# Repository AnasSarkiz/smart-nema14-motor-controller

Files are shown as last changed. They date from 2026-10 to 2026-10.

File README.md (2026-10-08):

# Active routing — 0.0.53-alpha.0

Read `docs/REV53-LOGIC-POWER-ESCAPES.md`. The canonical native replay retains
all56/120 complete nets, with240 required opens,128 tracks,82 ordinary0.30/0.45mm
full through vias,five manifested TypeVII thermal vias and seven filled regions.
Native other-errors:0; unchanged strict and filled-copper clearance failures:0;
GND remains one physical network. Original purchased definitions, all165 fitted
model transforms, capacitor placement, motor and carrier are preserved.
The complete USB_VDD bypass/return geometry is screened; V3V3 remains incomplete.
Continue3.3V/core power,PD/eFuse controls,USB pair and ALL remaining physical nets.
Publication is WIP; loaded power/USB/thermal,complete CAM,quote and hardware tests
remain pending. Do not stop at this step. PROTOTYPE FABRICATION READY:NO.

---

# Active routing — 0.0.52-alpha.0

Read `docs/REV52-VM-POWER-ROUTING.md`. Qualified power019 joins56/120 required
nets, including every RAW/protected-VBUS/VM terminal and all prior54 nets.
265 opens,112 tracks,79 ordinary0.30/0.45mm full through vias,five manifested
TypeVII thermal vias,eight native filled regions. Native other-errors:0; strict
and filled-copper clearance failures:0; GND remains one physical network.
Keep all supplier imports/models/placement unchanged. Continue3.3V and core
power,PD/eFuse controls,USB pair with return path,then ALL remaining connections.
Accepted main routes are phase0; VM fanouts phase2; new selected-net routing
is phase3 so existing power copper is a frozen obstacle. Publication is WIP;
loaded power/USB/thermal,complete CAM,assembly quote and hardware tests pending.
Do not stop at this checkpoint. PROTOTYPE FABRICATION READY:NO. No board order.

---

# Smart NEMA 14 Motor Controller

Revision **0.0.53-alpha.0 — WIP prototype** uses **RP2040** and **two USB-C ports**:
`J_USB` supplies motor power through STUSB4500 USB-PD; `J_DATA` connects the
computer's USB data. The board is 35 × 35 mm, four layers, with the original
STEPPERONLINE 14HM11-0404S motor and front carrier. Motor control is open loop.

Configure and read back STUSB4500 NVM for two active sink PDOs: 5 V bootstrap
and preferred 15 V / 1.5 A. Deactivate the factory 20 V PDO. The hardware
interlock combines the 15 V indication, live sink path, MCU request and logic
supervisor. Factory settings alone do not establish a 15 V motor contract.
Computer VBUS only supplies its presence-sense divider; computer power cannot
power the controller or motor. The POWER port must also be connected.

The checked copper connects **56/120 required nets**, including all raw/protected VBUS and all fifteen motor VM terminals: **128 traces, 82 ordinary
0.30 mm drill / 0.45 mm pad through vias, five filled/capped TMC2209 thermal
vias and seven native filled regions**. It has **240 open-port errors**, zero other
native errors and zero independent copper-clearance violations. Routing and
loaded power, USB, thermal and fresh manufacturing qualification continue.
**PROTOTYPE FABRICATION READY: NO. Not hardware tested.**

All 166 electronic references have purpose notes on eleven native A4 sheets;
165 are fitted (R50 is optional). Original official JLCPCB definitions and
OBJ/STEP models are preserved. Actual assembly, model registration and bounded
connector/cable checks pass. See [current routing evidence](docs/REV53-LOGIC-POWER-ESCAPES.md),
[two-port electrical review](docs/REV50-TWO-PORT-ROUTING.md),
[15 V NVM programming](docs/STUSB4500-15V-PROGRAMMING.md), [validation](VALIDATION.md)
and [Cloud task](docs/cloud/TASK.md). The remaining imported TVS schematic
rotation finding is disclosed. Exact-part stock checks are snapshots, not a
customer PCBA allocation or assembly quote.

The lockfile pins Bun 1.3.9, tscircuit 0.0.2757, CLI 0.1.2257, core 0.0.2107,
native Pipeline9 0.0.962 and coherent released dependencies.

```bash
bash scripts/cloud-setup.sh
bash scripts/cloud-smoke.sh
bun run typecheck
bun run build
```

Setup/startup do not route. The intermediate build exits 1 while required opens
remain. Routing uses bounded native Pipeline9 batches and qualified saved source
paths, without supplier edits, generated JSON edits or weaker checks.

Public destinations: [GitHub main](https://github.com/AnasSarkiz/smart-nema14-motor-controller)
and [tscircuit](https://tscircuit.com/AnasSarkiz/smart-nema14-motor-controller--01a0fd9b).
Publication receipts identify exact matching source, Circuit JSON and CAD bytes.
No fabrication order is authorized.

---

## Historical revision 48 record

The following is preserved history. Its one-port architecture, counts, toolchain
and CAD limitations do not describe the current two-port revision.

# Smart NEMA 14 Motor Controller

Revision **0.0.48-alpha.0** — **RP2040 + autonomous STUSB4500 USB-PD**.
**Partially routed prototype. PROTOTYPE FABRICATION READY: NO. Not hardware tested.**

The user-requested redesign replaces STM32/TCPP01 with official RP2040,
external 2 MB QSPI flash, 12 MHz crystal and a dedicated STUSB4500 sink with
back-to-back P-channel power switches. The former MCU had UCPD hardware but
qualified PD firmware was absent; USB-C alone did not establish working PD.
The new controller negotiates autonomously using its factory sink PDOs.
Firmware must qualify the actual contract before enabling the motor/current.

The CAN interface uses a new MCP2515 SPI controller and retains SN65HVD230.
A functional magnetic buzzer driver is added; TMP112 remains the I2C sensor.
Its sheet now includes the sensor, pull-ups, bypasses and buzzer circuit.
All **147 electronic references / 146 default fitted** have purpose notes on
nine native A4 sheets. Only R50, the optional CAN termination link, is DNP.

The board remains **35 x 35 mm, four layers**, with the original four
connectors, front carrier and exact **STEPPERONLINE 14HM11-0404S** single-front-
shaft motor. AS5600 stays removed; motor control is open loop.

See [the complete redesign and every review request](docs/RP2040-USB-PD-REDESIGN.md),
[current routing checkpoint](docs/REV48-ROUTING-CHECKPOINT.md),
[current validation](VALIDATION.md) and [Cloud task](docs/cloud/TASK.md).
Manufacturer pin/BOM and initial placement/model reviews permit routing.
Complete copper, power/USB/thermal/CAM qualification and hardware tests remain.
The full official schematic analyzer leaves one imported TVS rotation defect.
No purchased import, pad mapping, model, DRC or TypeScript rule is patched.

Fresh native [Circuit JSON](dist/index/circuit.json) contains **97 traces,
79 ordinary through vias and8 native ground pours**. **64 of108 required nets** have
one independently measured physical copper island. Native checking still
reports **227 open-port errors**, with zero other native errors and zero strict
copper/drill/edge/keepout violations in this partial build. The build exits1
because connectivity remains incomplete. It is not ready to order.
Old STM32 copper is preserved historically and deliberately cannot be replayed
against the new RP2040 pin selectors. Revision 43 Gerbers/exports cannot
manufacture this revision.

The reproducible lockfile uses Bun1.3.9, tscircuit0.0.2750 / CLI0.1.2254 /
core0.0.2105 / native Pipeline9 0.0.962 with coherent released dependencies.
Frozen installation succeeds through the official registry mirror with normal
TLS/integrity. No substitute router, dependency patch or proxy bypass is used.
Saving a Cloud draft alone does not activate its network policy.

All12 ICs and all146 fitted genuine STEP models pass actual CadQuery import,
solid validity and export/reimport. Current internal placements pass actual mounted146-mesh nominal envelope checks.
The native placement screen retains three orientation suggestions; they remain
explicit alongside the one imported TVS schematic-style finding.
All54 exact part numbers have positive official JLCPCB stock/SMT availability
checked2026-10-07 12:01UTC; customer allocation remains pending. The5-board
fitted-part baseline is$27.261 per board, excluding PCB, assembly/loading fees,
supplier losses, shipping/tax, carrier and motor. This is not a delivered quote.

```bash
bash scripts/cloud-setup.sh
bash scripts/cloud-smoke.sh
bun run build
bun run typecheck
```

Installation/startup do not route. Routing uses one bounded selected-net
native Pipeline9 job at a time on Linux through scripts/run-cloud-routing.py,
plus supported native saved manual paths. All56 current vias measure0.30mm
drill /0.45mm pad and span all four layers. Via-in-pad is disabled. Outer power,
complete loaded widths and USB coupling/return require copper qualification.

The standard JST programmer's five-pin order and protected SWD paths are
preserved. Its VOUT is isolated; independently power the target and use an
RP2040 programming target. The 38 wiring assertions pass; successful flashing
has not been tested.

Public destinations: [GitHub main](https://github.com/AnasSarkiz/smart-nema14-motor-controller)
and [tscircuit](https://tscircuit.com/AnasSarkiz/smart-nema14-motor-controller--01a0fd9b).
Publication receipts identify the exact successfully uploaded revision; a
local version number does not prove publication. The runtime packet includes
unchanged official OBJ/STEP dependencies and matching native JSON, excluding
old experiments. Full historical evidence and the tscircuit skill remain in Git.
No fabrication order is authorized.

The mounted native GLB has an empty J_SWD mesh after intermittent HTTP503
from the standard programmer's original model URL. The mechanical guard
reports145/146 fitted meshes measured, no carrier/fastener/pair collisions
among those145, and **fails** on the missing connector. A successful builder
exit does not qualify complete CAD rendering or fit. Original supplier models
and URLs are retained; no placeholder or changed component is substituted.

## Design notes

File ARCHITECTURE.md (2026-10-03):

# Current architecture — revision 16

Exact 14HM11-0404S, open-loop default. USB4110/C5143397 → TCPP01/C1121848 and STL11N3LLH6 → TPS26600RHFR/C2155767 → VM → TMC2209 and AP63203 3.3 V buck. Independent OUT rating allows reverse-blocked motor rail on USB removal; board is not rated 60 V. Isolated EFUSE_RTN is distinct from GND. Two 24 kΩ resistors select 0.50 A bootstrap /1.00 A contract-enabled current screen via low-voltage-specified DMG1012T-7. Motor sense pair is 1 Ω, 0.25 W; 10k/10k VREF yields about 0.32 A peak, conservative 0.34245 A screen. Two Panasonic 100 µF/35 V bulk capacitors, manufacturer-recommended buck capacitors and close bypass sites are retained.

Hardware pulls ENN high and CAN RS high at reset. Native MCU UCPD firmware is required for PD; TCPP only protects the port. Bootstrap allocation ≤150 mA at 3.3 V from a PD charger/dock advertising ≥1.5 A at 5 V. Motion only after qualified ≥1.5 A contract at 9/12/15/20 V, max source 21 V. External ports export signals/grounds, not 3.3 V power. SWD and VBUS sensing use powered-off-safe TMUX1511 gated by supply supervisor. U4/C6 and CAN termination link R50 are DNP by default. No rear encoder or rear screw mounting is claimed.

Four-layer 35×35 mm PCB mounts to four separate front-flange carrier supports. Exact official motor/USB models and unmodified supplier electronics are preserved. The configured native routing targets remain disabled in revision 16; actual copper is the next review. See VALIDATION.md, BOM-CURRENT.md and mechanical/POWER-CORNER-REVIEW.md for current limits/evidence. Firmware and physical tests remain pending.

## Historical architecture notes — earlier draft values and unresolved paths below are superseded by the current source

# Current revision 0.0.9-alpha.0 update

Selected motor: STEPPERONLINE 14HM11-0404S; 0.4 A/phase, 25 ohms,
24 mH, 0.9° (400 full steps/revolution), single front shaft. Previous motor
ratings/current-limit proposals and rear encoder mechanics below are retired.
No firmware current limit is implemented or tested. Optional AS5600 electrical
draft remains while feedback selection is pending. Motor attachment is blocked
pending rear fastener specification or a qualified carrier. Electronic supplier
imports and partial connectivity are unchanged; USB footprint/protection blockers
remain. See [current validation](VALIDATION.md).

## Previous electrical draft and historical motor proposals

# Architecture - partial schematic draft, not approved

## Power and startup

USB-C connector -> protected sink power path -> motor VM and 3.3 V buck.
Investigate the STM32G0B1 UCPD peripheral with TCPP01-M12 protection; retain
native PD as the proposed architecture. The TCPP01 is protection, not a
standalone PD-negotiation controller. MCU firmware must negotiate contracts.

Default USB 5 V must boot logic while the motor remains disabled by a hardware
pull-up on TMC2209 ENN. Firmware should select an offered PD contract,
prefer 12 V or 15 V when available, verify measured VBUS and negotiated current,
configure the driver and only then permit motion. Requesting 12 V cannot
guarantee that a particular source offers it. Support 9 V and 20 V where
offered. 5 V fallback is logic-only with ENN high; the chosen standard TMC2209
internal-regulator circuit requires at least 5.5 V. Never bridge 5VOUT to VM
in this multi-voltage design.

The startup supply, TCPP dead-battery behavior, MOSFET orientation, inrush,
connector-side capacitance, voltage sensing, overvoltage threshold and power
discharge still need a complete schematic and review. A bulk motor capacitor
must not be connected indiscriminately across unnegotiated VBUS; assess
isolating it with a controlled power path. Do not assume a MOSFET plus TVS
provides complete USB PD or regeneration protection.

The logic regulator draft now uses imported Diodes AP63203WU-7, C780769,
fixed 3.3 V with a 32 V operating input limit, 3.9 uH C19947652 / Bourns SRN6028C-3R9M, 10 uF/50 V
input, 100 nF bootstrap and two nominal 22 uF/25 V output capacitors.
Its VBUS_INRUSH_OUT input is not supplied yet. Upstream inrush/reverse-current
protection, effective capacitance, transient tests and thermal review remain gates.

## MCU and interfaces

Candidate STM32G0B1CBT6, C2847904, LQFP48/7 x 7 mm. The manufacturer
datasheet confirms USB FS, UCPD and FDCAN in this family. The 48-pin package
exposes UCPD1 CC pins PA8 and PB15 and USB PA11/PA12. The simultaneous candidate pin allocation is recorded in
references/MCU-PIN-PLAN.md. CAN uses PB5/PB6, preserving USB PA11/PA12.
MCU supply/reset, I2C, CAN and motor UART/STEP/DIR/ENN/DIAG connections
are instantiated. USB/CC frontend is now wired as a draft; downstream power, SWD and external IO remain unfinished.

Use MCU-generated STEP/DIR/ENN, UART and DIAG with the TMC2209. Receive
external STEP/DIR and limits through MCU inputs with defined pull states,
protection and documented logic levels. Do not short external STEP/DIR
drivers directly to actively driven MCU outputs.

Candidate CAN transceiver: TI SN65HVD230DR, C12084, 3.3 V. The imported part is instantiated in the CAN draft sheet
for classical CAN; no CAN FD data-phase support is claimed. Termination must
be selectable at endpoints. Connector pinout, protection and termination
switch remain unselected.

The C165948 USB-C connector draft carries PD and USB 2.0 data, with C94934
data ESD protection. Connector footprint approval is blocked by its difference
from the manufacturer drawing; C3020560 remains an unqualified alternative. Verify duplicated receptacle USB pins, return paths and the
final 90-ohm differential geometry against the chosen stackup.

## Programming

The official installed package exports `StandardJstSwdResetSide`, backed by
JST SM05B-SRSS-TB(LF)(SN), C136657. Its pinout is:

| Pin | Official signal |
| --- | --- |
| 1 | VOUT |
| 2 | SWDIO |
| 3 | GND |
| 4 | SWCLK |
| 5 | NRST |

**Pin 1 is programmer power output, not a confirmed passive VTREF input.**
The package describes a voltage selector. Resolve 3.3 V-only operation and
backfeed protection before connecting it to the USB-powered logic rail.
Verify the recommended series resistors and programming power arrangement
from the package's source/documentation. They have not been qualified.
No custom SWD connector is proposed.

## Motor current and temperature

0.3-1.0 A/phase is the typical target; 1.2 A/phase continuous is an intended
upper design target, **not a verified operating limit**. Resolve RMS versus
peak current conventions for the motor, driver configuration and advertised
limits. The current draft uses imported C5127775 / HoLRT1206-1W-180mR-1%, 180 mOhm,
1 W, 1%, giving nominal full-scale 1.149 A RMS / 1.477 A sine peak. This
conservative iteration targets no more than 1.0 A RMS in firmware, with 0.3 A
bring-up. It does not implement the approximately 1.2 A upper target. Exact
motor/nameplate convention, resistor tolerance/temperature, driver threshold
spread and actual thermal capability must be qualified before rating the board.

Provide the manufacturer-specified charge-pump capacitors, VIO and 5VOUT
decoupling, compact VM capacitance, grounded exposed pad, thermal vias and
ground-plane spreading. Select either an NTC/ADC network or a digital sensor
near the driver with firmware thermal shutdown and recovery rules.

A warm motor housing cannot be assumed to cool the driver. No numerical
1.2 A thermal qualification exists yet. Review the heat path, copper area,
ambient conditions and enclosure, then measure driver/PCB/motor temperatures
on an actual prototype. Determine a lower bring-up current before first motion.

Motor deceleration can return energy to VM. USB PD sources are not assumed
to absorb it. Define the load/inertia/speed range and size an energy absorption
or braking arrangement; TVS clamping voltage and energy must protect every
rail-connected component across tolerances.

## Encoder and mechanics

AS5600-ASOM, C79815, is the proposed optional bottom-side I2C encoder.
Its sensing center must align with the actual rear shaft and a diametrically
magnetized magnet. Verify the manufacturer's field-strength/air-gap limits,
package sensing location, magnet holder and assembly tolerance. The center
of a generic SOIC bounding box is not enough evidence.

The only modeled geometry is the requested 35 x 35 mm envelope. No holes
or shaft clearance have been guessed. STEPPERONLINE 14HS13-0804D-PG51 is a
possible reference because its page explicitly specifies a rear shaft and
rear screw holes, but it is a geared model and is **not the selected motor**.
The manufacturer's drawing has not been obtained/reviewed. Front NEMA hole
pitch cannot by itself qualify a rear mounting arrangement.

## Future route corrections

The installed props expose `pcbRouteCache` and native PCB trace/path APIs.
Once prior gates pass, retain each routed circuit JSON and its source/dependency
checksums before changing routes. Correct geometry in supported native source
or route-cache inputs, rebuild, then repeat shorts, clearances, drill-to-copper,
connectivity and visual checks. Never edit Gerbers or erase DRC records to
conceal a fault. No routes exist in this revision to save or edit.

References and the limits of each review are in `references/SOURCES.md`.

## Revision 0.0.6-alpha.0 schematic progress

The old critical label-loss issues are resolved through released converter output,
with the original audit unchanged. Five native A4 sheets now implement:

- STM32 power/reset and I2C1/FDCAN2 pin connections with imported passives.
- AS5600 at 3.3 V: both supply pins tied together, 100 nF, 4.7 kOhm I2C pull-ups,
  DIR grounded, OUT unused and PGO retaining its internal pull-up. This draft
  supports volatile configuration/readout only, not OTP programming.
- AP63203 with imported passives and a reviewed preliminary inductor ripple calculation.
- TMC2209, two 180 mOhm sense resistors, charge pump, 5VOUT/VIO/VM decoupling,
  200 uF nominal motor bulk, 10 kOhm ENN pull-up, STEP/DIR pull-downs, UART
  TX 1 kOhm and 5VOUT-derived VREF divider. No PCB thermal-via geometry yet.
- SN65HVD230 with 100 nF, RS grounded for high-speed classical CAN, VREF unused.
  The connector, ESD and selectable termination are still pending.

The regulator and motor support networks are present but their protected supply
inputs have no source yet. The separate VM input prevents a draft from implying
that the motor bulk can be connected directly to USB VBUS. Unwired MCU pins reserved for unfinished
blocks are intentionally visible; they are not declared as unused. Only actually
unused GPIO are marked no-connect and must be set to analog mode in firmware.
C2's nominal 4.7 uF must be checked for effective capacitance under bias.
No PCB coordinates are assigned. Encoder bottom-side intent does not establish
shaft alignment; all previews use PCB generation disabled.

TCPP physical pin 6 CTRLVBUS is the analog OVP divider input, not an MCU
control output. The pin plan was corrected before any such wiring was created.
TI TPS259470LRPWR / C3662793 was imported as an unused power-path candidate;
its presence does not qualify or implement the USB power path.

## Revision 0.0.7 USB frontend

See references/USB-PD-REVIEW.md for implemented pin connections, dead-battery
sequence, C0G replacement, OVP tolerance screen and explicit component blockers.
The protected output is not connected to buck or motor. No startup, PD contract,
overvoltage, reverse-current, current-limit or regeneration behavior is qualified.

## Revision 0.0.8 motor lock

Phidgets 3323_0 / 35STH40-1004B is the sole target motor. Motor rating
is 1 A/phase, superseding the earlier 1.2 A target. Until waveform/current
and thermal qualification, conservative proposed driver limits are 0.3 A RMS
bring-up and 0.7 A RMS maximum (approximately 0.99 A sine peak). These
limits are not implemented or verified firmware. Exact rear drawing and
original STEP are retained; the STEP's 4.0 mm rear shaft differs from the
drawing's 3.9 mm maximum. Diagnostic-only native assembly, proposed hardware
and remaining gates are described in mechanical/REVIEW.md. Routing is disabled.

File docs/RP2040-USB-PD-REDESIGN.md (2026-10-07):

# Active two-port continuation

The current RP2040 design requires separate 15 V motor POWER and COMPUTER
DATA USB-C ports. See [revision50](REV50-TWO-PORT-ROUTING.md) and the
[STUSB4500 programming procedure](STUSB4500-15V-PROGRAMMING.md). Earlier
one-port factory-PDO statements below are historical.

---

# Active routing — 0.0.47-alpha.0

Read docs/REV47-ROUTING-CHECKPOINT.md, VALIDATION.md and the manufacturer review
in docs/REV45-PRE-ROUTING-REVIEW.md. Current canonical copper connects54/108 nets:
85 tracks,56 ordinary0.30/0.45mm through vias,nine pours and249 open ports;
zero other native errors, native shorts or strict copper violations. GND has
one physical network. CAN TX/RX and one top-only motor winding are now saved.
Continue one bounded selected-net Pipeline9 job at a time, save qualified source
paths and correct actual DRC manually. Input-only diagnostics and public SDK
pre-repair capture never imply solved or qualified routes. All remaining54 nets,
loaded widths/USB/reference/thermal/fresh CAM and assembly quote remain open.
147 references/146 fitted genuine CAD records are unchanged from revision46.
Preserve original supplier imports/models/evidence, exact motor, connectors,
outline and carrier. Publish completed prototype steps with exact Circuit JSON
and CAD bytes under standing authorization. PROTOTYPE FABRICATION READY: NO.

---

# Historical revision46 continuation

# Active continuation — 0.0.46-alpha.0

Read docs/REV46-ROUTING-CHECKPOINT.md, VALIDATION.md and the manufacturer review
in docs/REV45-PRE-ROUTING-REVIEW.md. Current exact canonical copper connects
51/108 nets:82 tracks,52 ordinary0.30/0.45 mm through vias,nine pours and255
native open ports; zero other native errors or strict copper violations.
All147 references /146 fitted models /12 ICs pass actual CadQuery checks.
Fresh official stock checks pass all54 exact identities; allocation/quote pending.
Two C1570 30pF loads replace four parallel15pF loads and keep native CAN clocks
under10mm with zero vias. Three native placement orientation suggestions and
one disclosed imported TVS schematic rotation finding remain explicit.
Continue one changed bounded selected-net Pipeline9 job at a time, save qualified
source paths and correct actual DRC manually. Finish all copper, outer power
where feasible, USB return/impedance, current/thermal and fresh CAM/assembly
qualification. Preserve official imports/models/history, exact motor, outline,
four connectors and carrier. Publish completed prototype steps with matching
fresh Circuit JSON and original CAD hashes under standing authorization.
PROTOTYPE FABRICATION READY: NO. No fabrication order is authorized.

---

# Historical redesign notes

# Current RP2040 and autonomous USB-PD — 0.0.45-alpha.0

Read [the current manufacturer and routing review](REV45-PRE-ROUTING-REVIEW.md)
and [validation](../VALIDATION.md). Revision45 corrects the flash selection to
GD25Q16EEIGR/C2986331, USB terminations to27 ohm/C25100, adds the qualified-delay
RUN supervisor, and uses the correctly rated genuine B5819WS flyback clamp.
The coherent latest released toolchain installs and passes TypeScript. All53
exact JLCPCB identities have positive official stock/SMT snapshots; all12 ICs
and148 fitted genuine STEP models pass actual CadQuery validity/export checks.

The checked partial board has41/108 physically joined nets,61 tracks,28 ordinary
0.30/0.45mm through vias,0 pours and407 open-port errors. No other native error
or independent copper-clearance violation remains in this partial packet.
Both actual USB plug-orientation paths are connected; planar skew is0.409mm,
the ESD-to-termination trunk skew is0.195mm and MCUstub skew is0.100mm.
A supported native Bus applies the unchanged0.25mm limit to the actual two
trunks. Full plug paths retain the independent0.5mm limit. A branched connector
must not compare its short stub length with a different signal's entire trunk.
The long pair uses one common inner2 layer; actual coupling, via-barrel delay,
ground reference/impedance and complete routing/CAM remain unqualified.

The exact motor, four connectors, 35×35mm four-layer outline and carrier stay
unchanged. Only internal parts move for real USB escape/clearance defects;
original purchased definitions and model bytes are preserved. All149 references
have purpose notes on9 A4 sheets. The disclosed imported TVS orientation style
finding remains visible. The5-board fitted parts baseline is$27.27 per board,
excluding PCB/assembly/loading/supplier losses/shipping/tax/carrier/motor.
**PROTOTYPE FABRICATION READY: NO.** No order or hardware result is claimed.

The following revision44 description is preserved as historical evidence;
its old flash,33 ohm resistors, flyback, blocked toolchain and unrouted counts
are superseded by the current review above.

---

# Historical RP2040 and autonomous USB-PD — revision 0.0.44-alpha.0

This is a new, **unrouted prototype**, replacing the revision 43 STM32 MCU and
TCPP01 protection architecture at the user's request. The former STM32 had a
UCPD peripheral, but the repository did not contain qualified PD negotiation
firmware. A USB-C connector or TCPP01 alone did not establish working USB-PD.

## Actual circuit change

U1 is official RP2040 / C2040, with external 2 MB W25Q16JVUXIQ / C2843335 boot
flash, a 12 MHz ABM8-272-T3 / C20625731 crystal, supply bypasses, a 1.1 V internal
regulator reservoir and two 33 ohm USB data resistors. GPIO29 is unused. RUN is
pulled up; SWD is physical pin 25 and SWCLK pin 24. There is no BOOTSEL button in
this revision. Flashing via SWD and boot behavior still require firmware and
hardware testing.

U3 is official STUSB4500QTR / C2678061: an autonomous USB-PD sink on CC1/CC2,
with dead-battery connections, I2C address 0x28, bypasses, alert, reset and an
actual controlled back-to-back P-channel load switch. Q_PD_IN and Q_PD_OUT use
unchanged official STL8P4LLF6 / C222138 imports, common sources and common gates.
A 100 kohm gate-to-source resistor defaults the pair off; 22 kohm connects the
gate to the controller's active-low VBUS_EN_SNK output. The ST reference and
MOSFET manufacturer pin tables were read; complete protection review is open.

Factory sink PDOs are **5 V/1.5 A, 15 V/1.5 A and 20 V/1 A**. They are not a
promise that the connected charger supports them. Firmware must read the
actual negotiated RDO and measured VBUS before enabling higher current or the
motor. POWER_OK3 alone is insufficient. A preferred 15 V operating profile
needs qualified NVM configuration and charger compatibility. Do not enable a
1 A nominal eFuse limit against a 1 A contract without worst-case tolerance and
logic/motor current margins. The retained input limiter boots at nominal 0.5 A.

VBUS sensing uses a 1 kohm Panasonic ERJ-P08F1001V / C4261071 resistor. Two
parallel resistors of that same part discharge VM (effective 500 ohm). Each is
nominally 0.66 W; pulse, temperature derating and bulk-capacitance/discharge
timing qualification are pending. VDD has 470 ohm input filtering. The existing
25 V TVS and 40 V switch require a real transient coordination review against
the PD controller's limits. Nominal operation is not surge qualification.

RP2040 has no hardware CAN peripheral, so the existing CAN function now uses
official MCP2515T-I/ML / C96140 over SPI1 and a 16 MHz ABM8 crystal / C179641.
The SN65HVD230 transceiver and optional endpoint termination are retained.
Each crystal leg has two parallel 15 pF official capacitors (30 pF total);
crystal load/stray capacitance, oscillator startup, 3.3 V SPI clock limits and
bit timing need manufacturer and hardware qualification.

The formerly sparse I2C sheet now contains TMP112 at 0x48, its bypass/alert and
shared pull-ups, plus a functional C94598 MLT-5020 magnetic buzzer circuit:
GPIO25 PWM, official DMG1012T low-side switch, 100 ohm gate resistor, 100 kohm
default-off pull-down, 1N4148WS flyback clamp and 1 uF local bypass. This is a
circuit addition; drive current, acoustic performance, rail budget and carrier
clearance are not yet qualified. No duplicate temperature sensor or AS5600 is
added; the selected single-front-shaft motor remains open loop.

## Firmware interface

| RP2040 GPIO | Function |
| --- | --- |
| 0 / 1 | TMC UART TX / RX |
| 2 / 3 / 4 / 5 | TMC STEP / DIR / active-low enable / DIAG |
| 6 / 7 | I2C1 SDA / SCL (TMP112 0x48, STUSB4500 0x28) |
| 8 / 9 / 10 / 11 | SPI1 MISO / chip select / clock / MOSI |
| 12 / 13 | MCP2515 active-low interrupt / CAN transceiver standby |
| 14 / 15 / 16 | External STEP / DIR / active-low enable |
| 17 / 18 | Limit inputs |
| 19 / 20 | PD active-low alert / active-high reset |
| 21 / 22 | eFuse active-low fault / high-current request |
| 23 / 24 / 25 | Status LED / fault LED / buzzer PWM |
| 26 / 27 / 28 | VBUS ADC / PD POWER_OK3 / temperature alert |
| 29 | Unused |

Keep ENN high, high-current request low, buzzer off and CAN in standby at
reset. PD reset is active high and has a physical pull-down. The existing
standard JST programmer's VOUT stays isolated from target power; the target
must be powered independently. Its five-pin order and protection remain.
The updated independent 38-assertion check verifies wiring, **not successful
physical programming**. Use an RP2040 SWD/OpenOCD target, not STM32 firmware.

## Every review request and its actual status

| Review | Result / remaining work |
| --- | --- |
| RP2040 standardization | Implemented with genuine imports, flash and crystal; firmware and full manufacturer qualification pending. |
| Actual USB-PD | Dedicated autonomous STUSB4500 circuit implemented; NVM/contract/current/transient and physical tests pending. |
| Schematic readability | Nine functional A4 sheets, 147 purpose notes; sparse pull-up sheet fixed. Full official analyzer leaves one imported TVS rotation defect, not suppressed. |
| Standard USB-C symbol | Native standard symbol and all 16 purchased pad/pin groups checked. |
| JLCPCB availability | 147 exact supplier identities / 146 default fitted. Fresh official search has incomplete responses due HTTP 503; historical and initial candidate stock is not assembler reservation. |
| Placements and component correctness | New placement is checked natively and revised to improve actual bypass/crystal proximity. Manufacturer verification, route inductance/lengths and 3D fit remain gates. |
| Ordinary vias 0.30 / 0.45 mm | Configured through-via policy with via-in-pad disabled. There are zero generated vias: no claim of routed compliance. |
| No blind/buried vias | No vias yet. Verify every actual span after routing. |
| Power wires on outer layers | Required for new routing where feasible; no power traces exist yet. Old inner-power copper is historical. |
| Buzzer and I2C sensor | Complete source circuit added; retained TMP112 sensor. Drive/power/mechanical and routing qualification pending. |
| No shorts / opens / DRC | Placement build and explicit shorts screen reviewed separately. Explicit connection checks expose the missing new routes; board connectivity is incomplete. |
| Trace widths, power and USB | New copper, stackup, differential routing/return, current/thermal and regenerative-energy review required. Prior revision 43 metrics do not apply. |
| All 3D models | Official model dependencies must accompany publication; current dependency coverage is checked separately from actual mechanical fit. |
| Minimum runtime / circuit JSON | Dedicated runtime packet excludes old routing experiments. Fresh native JSON is required in all three mirrors. Old imports, copper and evidence remain historical in Git. |
| Updated tscircuit | Latest registry versions researched. Full upgrade fails on published modelprinter dependency at blocked pkg.pr.new; original frozen pins retained, not substituted. |
| Push to tscircuit | Publish a clearly labeled unrouted prototype only after applicable checks; exact public file hashes and matching GitHub commit must be verified. |
| Ready to order | **NO.** Stages 2/3 remain in progress; no routing/fabrication/hardware approval follows from installation or a zero placement-error count. |

Manufacturer hosts and `pkg.pr.new` are saved in the environment draft, retaining
the package-manager preset and existing install/startup instructions. The
configuration tool says **requires_publish**: review/save in environment
settings, then publish the environment to apply the policy. A saved draft is
not effective runtime access. No proxy bypass, package substitution, credential
copy or TypeScript/DRC reduction is used.

The 35 x 35 mm four-layer outline, four connectors, front carrier and exact
STEPPERONLINE 14HM11-0404S are retained. Revision 43 routing modules, models,
context manifests and evidence are preserved historically. Replaying STM32
pin selectors against RP2040 is explicitly rejected. Previous Gerbers and
qualification ZIPs cannot manufacture this revision.

**PROTOTYPE FABRICATION READY: NO. No fabrication order is authorized.**

The mounted native GLB has an empty J_SWD mesh after intermittent HTTP503
from the standard programmer's original model URL. The mechanical guard
reports145/146 fitted meshes measured, no carrier/fastener/pair collisions
among those145, and **fails** on the missing connector. A successful builder
exit does not qualify complete CAD rendering or fit. Original supplier models
and URLs are retained; no placeholder or changed component is substituted.

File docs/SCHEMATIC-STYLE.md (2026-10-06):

# Schematic style review — 0.0.42-alpha.0

The user's UI screenshot shows eleven issues on 0.0.40. The full current
official analyzer also reproduces eleven issues on the canonical 0.0.41 JSON.
Revision 0.0.42 reduces that result to **one unresolved issue**, D_VBUS
orientation. No style rule, DRC threshold or imported definition is changed.

| Issue | Source correction |
| --- | --- |
| J_USB box width | Native USB-C wrapper width 1.65 instead of 1.70; all sixteen official pin groups retained |
| U8 inner pin-label collision | Board-owned schematic width increased to 1.80 |
| Six separated capacitor banks | MCU, motor, buck, USB and programming capacitor schematic positions brought closer together |
| U1 reset supply path | Reset pull-up/filter moved to the MCU's reset side |
| U8 ground path | Local native GND label; reset pull-up moved closer |
| Additional automatic U10 ground detour during iteration | Local native GND label |

These changes affect schematic drawing only. The preservation check compares
every purchased manufacturer-pin electrical partition, part/pin attributes,
every PCB element type, placement and CAD registration with 0.0.41. It ignores
generated identifiers while resolving physical-port references to their real
component and manufacturer pin. All 411 purchased pins and all physical PCB/CAD
records remain exact. Original supplier modules and local model bytes are
unchanged. There is no new autorouting search.

## Analyzer and repeatable checks

Official analyzer source:
https://github.com/tscircuit/circuit-json-schematic-placement-analysis/tree/3b42ebf254bb5d7343874d3ec1023cc63a7781ce
(package manifest 0.0.45). The complete default analysis is used, without issue
filters. Its own native issue artifacts are rendered for review.

The pinned CLI's schematic-placement command runs an older, smaller analysis;
its successful exit status does not mean the full UI style analysis is clean.
The current official source reproduces the reported USB width warning even
though the analyzer bundled into the installed checks exempts native USB-C.
The board-owned width correction passes the full analyzer without exemptions.

The UI imports its analyzer from `jscdn.tscircuit.com`. That host returns proxy
403 in this VM. An exact live CDN/browser result is **not** claimed. To enable
that additional check, add only `jscdn.tscircuit.com` in environment network
settings and retry; do not replace the existing allowlist or bypass the proxy.
The official GitHub analyzer source executes locally using the existing pinned
runtime dependencies; no board dependency or lockfile changes are needed.

Example isolated review checkout, from the repository root:

```bash
git clone https://github.com/tscircuit/circuit-json-schematic-placement-analysis.git .publication/style-analyzer
git -C .publication/style-analyzer checkout 3b42ebf254bb5d7343874d3ec1023cc63a7781ce
ln -s "$PWD/node_modules" .publication/style-analyzer/node_modules
bun scripts/check-schematic-style.mjs dist/index/circuit.json .publication/style-analyzer/lib/analyze-schematic-placement.ts /tmp/schematic-style.json
python3 scripts/check-schematic-preservation.py /tmp/rev41-circuit.json dist/index/circuit.json /tmp/schematic-preservation.json
```

Use the immutable 0.0.41 baseline JSON from commit
`9f7ca62d598f61154ac4be2bc9db2debd83678d1` for `/tmp/rev41-circuit.json`.
The full style command correctly exits **1** while D_VBUS remains unresolved;
its report retains every issue and does not turn a known failure into a pass.

## Remaining imported-symbol defect

D_VBUS is official ESDA25P35-1U1M / C1974707. Its imported React `<symbol>`
remains horizontal despite the already requested native `schRotation={270}`.
The installed core's schematic transform translates these React primitives;
it does not apply the requested chip rotation. Changing the rotation number or
wrapping it in a group does not supply the missing runtime rotation.
The existing unmodified import reproducer is
`scripts/imported-symbol-rotation.circuit.tsx`.

This needs a supported upstream core/importer repair before complete schematic
qualification. No custom replacement symbol, dependency patch or generated-JSON
edit is adopted. The physical purchased pins and footprint remain verified.
Some automatic value labels still overlap wires; a zero style count would not
by itself establish readability, electrical correctness or fabrication readiness.

All prior fabrication blockers remain: MCU sourcing, supplier silk/orientation,
uniform requested vias, outer-only power, full power/thermal and manufacturer
process/assembly qualification. Firmware and hardware tests remain pending.
**PROTOTYPE FABRICATION READY: NO.** No fabrication order is authorized.

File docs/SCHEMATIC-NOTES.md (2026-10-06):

# Schematic component explanations

Revision 0.0.40-alpha.0 explains every one of the 109 electronic references inside
the native schematic. Each A4 sheet has a right-side COMPONENT PURPOSE panel,
with values and a short description of each device, passive or connector.
U4/C6 are removed. R2/R3 remain for U9 temperature monitoring; R50 is the
optional CAN endpoint link (DNP, do not populate). The default fitted count remains 108.

Native USB-C standard symbols and the explanatory panels are retained. Revision
40 removes U4/C6 and their notes, renames Encoder to I2C, and reconnects shared
PCB bus/power/ground copper. Remaining purchased placements, pads and CAD are
unchanged. The original component imports and model assets remain intact.

All nine native renders were viewed; the coverage/layout check requires one
explanation per reference on its matching sheet and a panel clear of symbols,
net labels and wiring. TypeScript, format, native build, netlist, shorts, placement
and source checks pass. Existing 30 route-width and 24 supplier-pin metadata
warnings remain disclosed. The snapshot command records a new visual baseline.

Run `bun run test:schematic-notes` on fresh canonical Circuit JSON and
`node scripts/render-schematic-sheets.mjs` to reproduce the individual images.

- [MCU](../evidence/rev-0.0.40-alpha.0/schematic-MCU.png)
- [I2C](../evidence/rev-0.0.40-alpha.0/schematic-I2C.png)
- [CAN](../evidence/rev-0.0.40-alpha.0/schematic-CAN.png)
- [LogicPower](../evidence/rev-0.0.40-alpha.0/schematic-LogicPower.png)
- [MotorDriver](../evidence/rev-0.0.40-alpha.0/schematic-MotorDriver.png)
- [UsbPd](../evidence/rev-0.0.40-alpha.0/schematic-UsbPd.png)
- [Programming](../evidence/rev-0.0.40-alpha.0/schematic-Programming.png)
- [Interfaces](../evidence/rev-0.0.40-alpha.0/schematic-Interfaces.png)
- [InputPower](../evidence/rev-0.0.40-alpha.0/schematic-InputPower.png)

PROTOTYPE FABRICATION READY: NO. Supplier silk, four CPL orientations,
four sourcing/allocation gaps, stackup/plating/filled-via acceptance and complete
power/thermal qualification remain open. Hardware and programming are untested.

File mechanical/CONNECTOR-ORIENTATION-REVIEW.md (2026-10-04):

# Connector orientation review — 0.0.19-alpha.0

All four actual native 3D connector openings face outward. No electronic rotation or placement correction is required. Each connector is side entry; the whole connector body need not sit flush with the board edge. The plug must have a clear outward insertion and straight cable exit corridor.

| Reference | Exact connector / JLCPCB | PCB side / rotation | Cable exit viewed from above | Outer model setback from PCB edge | Remaining screened plug clearance |
| --- | --- | --- | --- | --- | --- |
| J_USB | GCT USB4110-GF-A / C5143397 | top / 0° | lower edge, −Y | −0.090 mm (slight protrusion) | 2.2331 mm |
| J_MOTOR | JST SM04B-GHS-TB / C189895 | top / 180° | upper edge, +Y | 3.2670 mm | 2.0643 mm |
| J_IO | JST SM10B-SRSS-TB / C160409 | bottom / 90° | right edge, +X | 0.8620 mm | 0.1643 mm |
| J_SWD | JST SM05B-SRSS-TB / C136657 | top / 90° | right edge, +X | 0.4625 mm | 1.0385 mm |

Setbacks measure the exported model's outer bound, not an independently dimensioned mouth datum. Rotation numbers alone do not establish opening direction. J_IO's generated bottom CAD rotation is Y=180°/Z=270°; its actual exported mouth was reviewed from both sides and points +X. The manufacturer's SH and GH side-entry drawings were rendered and inspected alongside the model views. GCT exact STEP registration and the imported footprint audits remain applicable.

All 111 current component placements and CAD registrations exactly match the mounted model input. Every connector SMT land matches, including the bottom layer. Fresh exact carrier/fastener versus all 111 mesh-envelope checks pass, and the constrained mating screen was rerun. The minimum I/O margin is 0.164285 mm after 0.40 mm static allowance and 0.135715 mm analytical load deflection; this is tight and needs a physical fit test with SHR-10V-S/AWG28. JST actual mating STEP models remain unavailable; the plugs are explicitly drawing-based clearance envelopes. USB overmold ≤12×7 mm; route wires straight outward beyond the reviewed envelope before bending. Do not bend them inward toward the motor or carrier.

The native placement check reports zero errors/warnings. Formatting and TypeScript pass. No purchased definition, footprint, pin mapping, placement, electronic wiring or saved copper changed. The prior five native checks and partial-copper audit remain applicable. This review does not complete the 88 unfinished connections, final copper/current/thermal/USB checks, CAM or physical tests. The design remains an untested routing prototype.

Evidence: `evidence/rev-0.0.19-alpha.0/connector-orientation/ORIENTATION-REVIEW.json`, four isolated opposite-view renderings, connector-access overview, rendered manufacturer drawings, exact input hashes and correspondence report. The overview uses native geometry without the PCB artwork texture, and omits the motor to expose the underside. The separate mounted assembly still contains the exact unchanged motor.

Reproduce the rendered review from a matching mounted export and current partial circuit:

```sh
.mechanical-venv/bin/python mechanical/render-connector-orientation.py --current-circuit evidence/rev-0.0.19-alpha.0/current-partial/circuit.json --mounted-circuit dist/mounted-assembly/circuit.json --glb dist/mounted-assembly/3d.glb --output-dir evidence/rev-0.0.19-alpha.0/connector-orientation
.mechanical-venv/bin/python mechanical/check-front-carrier.py
python3 mechanical/check-carrier-tolerance.py
.mechanical-venv/bin/python mechanical/check-mating-envelopes.py
```

The renderer asserts current placement/CAD/land correspondence before accepting historical mounted geometry. Rebuild mounted geometry if these assertions fail. Dist files are reproducible build outputs; hashes identify the exact inspected input. Rendered images are not physical photos or physical test evidence.

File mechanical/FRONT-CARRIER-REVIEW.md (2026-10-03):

# Front-flange carrier — revision 0.0.16-alpha.0

Unfabricated mechanical prototype for the exact STEPPERONLINE 14HM11-0404S. The manufacturer drawing and STEP are unchanged. Four front M3 holes on the documented 26 ±0.2 mm square attach the carrier. Motor rear structural screws remain untouched.

The 35 × 35 mm PCB has four Ø2.5 mm NPTH holes on a 30.5 mm square with all-layer 2.5 mm radius keepouts. The monolithic machined 6061-T6/T651 carrier has a 49.2 × 36.5 × 3 mm front plate, Ø24 mm pilot opening, Ø3.8 mm front bolt clearances, four direct 6 × 6 mm rails and Ø4.5 mm PCB support bosses. Motor rear/front datums are Z=-10/-38.2 mm; PCB midplane is Z=0 and support surface -0.8 mm. Returns end at -4.8 mm below the PCB. Proposed machining tolerance is ±0.05 mm.

The actual exported 111 component mesh envelopes clear the exact carrier and fastener solids by at least 1.000005 mm. There is no carrier/motor intersection. The fresh mounted rendering was inspected. The analysis includes fitted and DNP component bodies conservatively. Production component models, actual hardware installation and strength are not physically verified.

JLC04161H-3313 is ordered as 1.6 mm but the live manufacturer calculator displays 1.56 mm finished, ±10%. Calculations use minimum PCB thickness 1.404 mm, and include the 1.6 mm rendering offset in the clearance allowance. A single rail carries the entire declared 20 N cable/board load in the cantilever screen. Conservative combined rail/arm/PCB deflection is 0.1357 mm and section stress safety factor 10.81. FR4 modulus is an engineering allowance, not a laminate guarantee. This is not FEA, fatigue qualification or a physical load test.

Permitted hardware envelopes: M2×5 length 5 ±0.2 mm, head ≤Ø3.8 ×1.6 mm, custom washer Ø4.5/Ø2.2 ×0.50 ±0.05 mm; M3×6 head ≤Ø5.5 ×3 mm. Screened M2 engagement is 2.484–3.396 mm versus 4.45 mm minimum thread envelope; front screw penetration is 2.75–3.25 mm versus the motor's 4 mm minimum available depth. These are dimensional procurement constraints, not a claimed purchased hardware model. Retention, preload, torque, insulation and physical installation remain Stage 7 tests.

Drawing-based conservative mating envelopes pass after an additional 0.40 mm static allowance plus the calculated load deflection. Remaining clearances: I/O 0.1643 mm, SWD 1.0385 mm, motor plug 2.0643 mm and USB 2.2331 mm. I/O: JST SHR-10V-S / SSH-003T-P0.2-H AWG28; SWD: SHR-05V-S / same contacts AWG28; motor: GHR-04V-S / SSHL-002T-P0.2 AWG26. USB cable overmold must fit ≤12 mm width ×7 mm thickness. Route all wires straight outward beyond the audited envelopes before bending. JST exact mating CAD requires an emailed download and was unavailable; these are explicit clearance envelopes from reviewed manufacturer drawings, not substitute exact component models.

Repeatable evidence: FRONT-CARRIER-AUDIT.json, CARRIER-TOLERANCE-SCREEN.json and MATING-ENVELOPE-AUDIT.json under evidence/rev-0.0.16-alpha.0/. The normal assembly is mounted-assembly.circuit.tsx; the +65 mm exploded view is inspection only. These checks authorize the next PCB routing stage for the bounded prototype; they do not approve hardware strength, arbitrary harnesses or fabrication orders.

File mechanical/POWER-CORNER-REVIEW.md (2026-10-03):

# Power disconnect and regeneration review — revision 16

Analytical screens only. Routing is disabled; no hardware test or fabrication readiness is claimed. Exact calculation inputs and results are in evidence/rev-0.0.16-alpha.0/POWER-CORNER-SCREEN.json.

TPS26600RHFR/C2155767 replaces TPS25947. OUT is rated independently to 60 V operating / 62 V absolute, so the previous input-relative limit on USB removal is resolved. The complete system remains limited by TMC2209's 29 V operating maximum and lower component/interface limits. MODE is tied to separate RTN for current-limit/automatic retry. GND and RTN must remain isolated in copper. SHDN's internal pull-up enables cold startup; the motor ENN remains pulled high. Current limiting is nominal 0.50 A bootstrap and 1.00 A after a qualified PD contract, using two official 24 kΩ resistors and low-voltage-specified DMG1012T-7. The screened boot range is 0.4167–0.5867 A; the parallel range is 0.9314–1.0714 A. These are engineering screens; physical measurements are pending.

Proposed prototype limits: USB-C PD charger/powered dock advertising at least 1.5 A at initial 5 V; 9/12/15/20 V contracts, source no higher than 21 V, contract current at least 1.5 A before raising POWER_HIGH_CURRENT. Hold ENN high at 5 V, on disconnect or fault. Legacy/default-current USB hosts are not qualified. Target phase peak screen is 0.34245 A without credit for internal sense resistance. Limit speed to 300 RPM and external reflected inertia to 0.25×10⁻⁶ kg·m²; exclude continuous backdrive/overhauling. These are proposed design limits, not measured operating ratings.

At 28.8 mH maximum phase inductance, independently bounded phases plus rotor/load kinetic energy total 3.994 mJ. Two 100 µF Panasonic FP capacitors are screened at 100.8 µF combined after −20% initial tolerance, −10% reflow and −30% endurance allowances from the current manufacturer datasheet. Lossless VM rises from 21 V to 22.809 V. A conservative low-frequency tanδ/resistive-step screen gives 24.972 V. High-frequency parasitic overshoot is not included; short native power loops, appropriate planes and prototype measurements remain required. This is not a claim of transient certification or a brake for arbitrary loads.

The OVP divider screens 21.473–22.843 V including resistor temperature allowance, threshold limits and input leakage. C33 is 2.2 µF directly between dVdT and RTN. C34 is 2.2 µF at the protected input. Typical Taiyo Yuden bias/temperature charts, ±10% initial tolerance, 15% temperature and 20% aging allowances give a 1.330 µF dVdT screen and 0.186 µF input bypass at 21 V; these curves are typical rather than guaranteed combined limits. Maximum screened VM charging current is 28.5 mA. AP63203 soft start is 4 ms typical with no stated minimum; the paper bootstrap allocation is reviewed below; actual cold-start timing and firmware remain physical qualification items.

Primary references: [TI TPS2660](https://www.ti.com/lit/ds/symlink/tps2660.pdf), [Panasonic FP 2025](https://industrial.panasonic.com/cdbs/www-data/pdf/RDE0000/ABA0000C1184.pdf), [Taiyo Yuden exact capacitor characteristics](https://ds.yuden.co.jp/TYCOMPAS/ut/detail?pn=MSASU168BB5225KTNA01&u=M), [Diodes DMG1012T](https://www.diodes.com/datasheet/download/DMG1012T.pdf), and [AP63203](https://www.diodes.com/datasheet/download/AP63200-AP63201-AP63203-AP63205.pdf). Reference files and chart provenance remain in references/.

## Bootstrap allocation and sequencing

Until a qualified PD contract, limit total 3.3 V logic demand to 150 mA, keep ENN high and CAN RS high, omit the encoder, and export no logic supply on either signal connector. This allocation exceeds the ST MCU all-peripherals-disabled 64 MHz characterization (9.9 mA max at 130 °C); peripheral/I/O demand must remain within the allocation. TI specifies CAN standby at 0.6 mA max, TMUX1511 at 70 µA max, TLV803E at about 1 µA max, and TMC2209 disabled VM current at 10 mA max under its stated clock/test conditions. Separate engineering allowance covers those VM/control loads. LED/pull-up loads are included in the allocation. External signals must be 3.3 V logic or dry-contact limits, with no back-powered load or power export.

Using 3.465 V output, 4.2 V VM, a conservative 60% efficiency allowance, 10 mA disabled driver, 5 mA additional control allowance and 28.48 mA bulk charging gives 0.24973 A screened bootstrap demand, leaving 0.16694 A below the 0.41667 A low current-limit screen. The source sees at most 0.59167 A screened eFuse/control load versus its required ≥1.5 A advertisement. The converter has no guaranteed minimum efficiency or soft-start duration; this engineering calculation does not establish cold-start waveforms. Actual start, brownout and PD-contract transitions remain Stage 7 measurements. Normal post-contract logic allocation remains ≤0.3 A.

The paper schematic/BOM review can proceed to routing for this bounded programmable prototype. Physical PD negotiation and contract-aware protection firmware are not delivered. Keep the hardware-default motor-disable/CAN-standby states until firmware validates the actual source, current, rail voltage and fault inputs. Firmware must hold ENN high on disconnect/fault and configure the motor before motion. High-frequency transient and temperature measurements remain explicit prototype tests after the actual copper layout is reviewed.

Startup references checked 2026-10-03: [ST DS13560 Rev 6](https://www.st.com/resource/en/datasheet/stm32g0b1cb.pdf), [TI SN65HVD230](https://www.ti.com/lit/ds/symlink/sn65hvd230.pdf), [TMC2209 Rev 1.09](https://www.analog.com/media/en/technical-documentation/data-sheets/TMC2209_datasheet_rev1.09.pdf), and the TI TMUX1511/TLV803E/TMP112 references already preserved locally.

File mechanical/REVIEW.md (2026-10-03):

# Current mechanical scope — revision 0.0.13-alpha.0

The selected motor remains STEPPERONLINE **14HM11-0404S**. Its drawing is
**A0217 revision 0, 2025-07-31**; the historical revision-1 statement below
was incorrect. No manufacturer geometry was changed. The default review BOM
omits U4/C6 and makes no encoder-feedback claim. USB4110-GF-A C5143397 now
passes the manufacturer footprint and exact external-model registration checks;
old USB alternatives below remain unselected historical findings.

The exported native connector CAD and unchanged official motor STEP were
rebuilt with CLI 0.1.2237 and EasyEDA 0.0.369. All 112 CAD objects are present,
and the actual USB GLB vertices pass registration checks. These limited checks
do not approve a mounting carrier, mating cable, harness, tolerances or thermal
fit. The motor remains lifted +65 mm for inspection; the board is unmounted.
Routing remains disabled. Current evidence: `evidence/rev-0.0.13-alpha.0/`.

## Historical mechanical records — superseded where stated above

# Revision 0.0.10-alpha.0 visualization update

Motor raised +65 mm along Z; actual controller shown below in an exploded view.
No separate cover is modeled. This is inspection spacing, not mounting geometry.
Board close-up temporarily hides the motor. Rear mounting/encoder qualification
remains blocked as described below. Official STEP and supplier definitions are
unchanged. Evidence: `evidence/rev-0.0.10-alpha.0/`.

# STEPPERONLINE 14HM11-0404S mechanical review

Revision 0.0.9-alpha.0, 2026-10-03. **Mount unqualified; routing disabled.**

The user selected this exact motor in place of Phidgets 3323_0. The unchanged
STEP and full datasheet downloaded from the [official product](https://www.omc-stepperonline.com/nema-14-bipolar-0-9deg-11ncm-15-58oz-in-0-4a-10v-35x35x28mm-4-wires-14hm11-0404s)
are in `references/motor/14hm11-0404s/`. The PDF drawing A0217 rev. 1 was
rendered to `evidence/rev-0.0.9-alpha.0/motor-drawing.png` and inspected. The STEP
SHA256 is `959f43e95b7840beae5ffbd56e997e23c5004a1b09e16b7caa40400296e46281`.

OpenCASCADE imported one valid solid. Source datums: front face Z=0,
rear face Z=28.2, shaft end Z=-24. The native TSX uses the rear face as world
origin, moving the front face to Z=-28.2 and shaft end to Z=-52.2.
No generic geometry or altered vendor STEP is used. Native GLB and viewer show
this reference alone, and the previous motor/PCB mounting proposal is retired.

The drawing specifies a single Ø5 mm front shaft, 24±1 mm projection;
4×M3 front holes on a 26±0.2 mm square, depth ≥4 mm. The original 2×M1.6
Phidgets rear pattern does not apply. STEP shows rear corner recesses/fasteners
at (±13,±13), but the drawing does not qualify those as controller attachment
points or specify replacement screw length, thread engagement or preload.
Obtain a manufacturer specification or design a separate qualified carrier
before choosing posts/holes. Do not remove structural motor screws on an assumption.

Encoder feedback is optional. This single-shaft motor cannot use the previous
rear-shaft magnet. The user has asked whether an encoder is necessary; no omission
or relocation has yet been approved. Optional electrical draft remains retained.
A front-mounted encoder would need a separately qualified mechanical arrangement.

The vendor STEP header is dated 2018, while the supplied drawing revision is
2025. Both are the official files currently linked for this SKU; their complete
revision compatibility and physical purchased hardware remain unverified.
The STEP's full bounds include modeled wires; approximate BRep bounds are not a
measurement of frame size alone. No frame-dimension mismatch is asserted from
those approximate bounds.

Inspect `dist/assembly/3d.glb`, `3d.png`, `circuit.json` and the offline
`mechanical/assembly-preview.html`. The separate `dist/controller-preview/`
is an unmounted placement draft. PCB, hardware, sensor, connector and cable fit
together **has not passed**. USB footprint blockers remain, including C165948
and the unselected C3020560 alternative. No fabrication readiness claim is made.

## Historical Phidgets review — superseded mechanical target

# Phidgets 3323_0 motor-mounted diagnostic assembly

Revision 0.0.8-alpha.0, 2026-10-03 Europe/Tirane. **Mechanics blocked;
routing disabled; not fabrication ready.** This file supersedes the earlier
unknown-motor requirement. It does not pass a complete-board validation stage.

## Authoritative motor and encoder sources

- [Phidgets 3323_0 product](https://www.phidgets.com/?prodid=342), model
  35STH40-1004B. 1 A/phase, 2.7 ohm, 4.3 mH; the earlier 1.2 A target is
  retired. Proposed firmware limits require RMS/peak and thermal qualification.
- [Official drawing 0DZ.252.001](https://www.phidgets.com/productfiles/3323/3323_0/Documentation/3323_0_Mechanical.pdf),
  retained unchanged in references/motor/3323_0_Mechanical.pdf and visually
  inspected after rendering. Rear view is used, wires toward -Y.
- [Official STEP ZIP](https://www.phidgets.com/productfiles/3323/3323_0/Images/3323_0_3D.zip),
  retained unchanged; its single 3323_0.stp is extracted byte-for-byte.
  OpenCASCADE imports centimetre STEP source units into millimetres.
- AMS AS5600 datasheet v1-02, 2015-Nov-13, from the
  [official component supplier](https://datasheet.lcsc.com/datasheet/pdf/fab02cf30a2c48b5aeeebf03db9fe675.pdf?productCode=C79815).
  Original manufacturer URL returned 404 and no replacement datasheet is
  invented. Reviewed rendered pp. 33-35: package-centered Hall array, 6 mm
  magnet displacement guidance of 0.25 mm, typical 0.5-3 mm air gap,
  SOIC8 dimensions and AGC qualification requirement.

## Exact geometry lock and model findings

| Feature | Official drawing / requirement | Original STEP measurement |
| --- | --- | --- |
| Rear shaft diameter | 3.9 +0/-0.15 mm | **4.0 mm: discrepancy, B014** |
| Rear shaft projection | 12 +0.7/-0.3 mm | 12 mm nominal |
| Rear mounting | 2 x M1.6 through PCB, circle 14.5 +/-0.15 mm | 14.5 mm, modeled minor bores 1.221 mm |
| Rear hole line | 40 degrees from +X in rear view | 40 degrees |
| Screw depth into motor | Strictly below 2.5 mm | Proposed male stud 2.0 +/-0.1 mm; maximum 2.1 mm |
| Motor body | 35.2 mm maximum, 40 mm axial length | 34.95 x 34.95 x 40 mm |
| Front features | 4 x M3 / 26 mm; excluded from PCB rear mounting | Retained only in the original motor model |

Native PCB rear hole centers are exactly +/-(5.553822212612591,
4.660210170227409) mm. Clearance-hole diameter 2.2 mm is a proposal,
not a 2.2 mm thread or altered motor hole. AS5600 native center and magnet
axis are (0,0), bottom sensor faces the magnet. Native CAD retains the
importer's model origin; its encoder origin rounding is 0.0000127 mm.
Nominal centering does not establish physical assembly alignment.

World origin is the PCB mid-plane. PCB is 35 x 35 x 1.6 mm. Motor rear
face is Z=-19.1 mm; original model rear-plane datum (-17.475,17.475,0)
is translated and rotated 180 degrees about X. Motor body extends toward
-Z and rear shaft points toward the PCB. No generic motor geometry or
manually edited original STEP is used.

## Proposed mechanical hardware — not sourced or approved

Generated CAD describes mechanical envelopes only, not electronic component
definitions. All electronic definitions and their CAD metadata remain the
unchanged official supplier/package outputs.

- Nonmagnetic standoffs: 18.3 +/-0.05 mm long, outside diameter 3.2 mm,
  M1.6 male projection 2.0 +/-0.1 mm, top female threaded envelope. Model
  includes proposed 4 mm top screw, 0.3 mm washer and 3.2 mm head envelope.
  Threads are major/minor clearance envelopes, not detailed thread profiles.
  Major-thread overlap with the motor's minor bore is an intentional modeled
  thread-engagement exception; procurement, torque and vibration remain open.
- Nonmagnetic retaining cup: 4.05 mm bore, 8 mm outside diameter, 0.3 mm
  floor, proposed adhesive/jig alignment. The loose bore is not a centered
  press fit. Retention, runout, shaft/motor discrepancy, material, temperature
  and manufacturing tolerances require qualification.
- Diametrically magnetized 6 x 2.5 mm magnet envelope. Exact magnet supply,
  magnetization/field and tolerances are not qualified; no candidate is
  presented as a purchased approved part.

Measured nominal magnet-to-package surface gap: 1.8 mm. Conditional stack
range: 0.8-2.7 mm, using 11.7-12.7 mm shaft projection, proposed floor
0.2-0.4 mm, proposed magnet height 2.4-2.6 mm, standoff 18.25-18.35 mm,
package A maximum 1.75 mm and A2 minimum 1.25 plus A1 minimum 0.10 mm.
This excludes solder height, retention, axial end-play not specified by the
drawing, thermal movement and magnetic qualification. The typical data-sheet
gap range is not an operating guarantee. Check AGC/field and angle performance
on a physical prototype.

The 2.2 mm PCB holes around M1.6 fasteners permit 0.3 mm radial movement,
already larger than the 0.25 mm magnet-axis allowance before adding placement,
motor-hole and magnet-runout tolerances. An axis registration/jig process and
qualified hardware tolerances are required; CAD nominal coordinates alone
do not pass this requirement (B003).

## Actual assembly and visual review

assembly.circuit.tsx uses native assembly.device / assembly.subassembly /
cadmodel APIs from installed core 0.0.2052 / props 0.0.676, verified in local
source and [official documentation](https://docs.tscircuit.com/elements/assembly-subassembly).
It reuses all 56 actual draft supplier components, adds unchanged official
C136657 programmer connector as a separate mechanical envelope and native
rear holes. Programmer VOUT is deliberately unconnected in the fixture;
functional power integration remains unresolved in the main design.

Only the diagnostic view uses these provisional coordinates. This is not an
approved high-current/decoupling/routing layout. Motor, CAN, STEP/DIR and
limit connectors and their mating cables are not selected and cannot be
qualified or shown as completed geometry. USB/C136657 models are present;
full cable/mating access remains unqualified. The programming connector was
rotated toward the right edge after an insertion-direction warning.

Current native PCB PNG, 3D PNG, GLB and interactive viewer were inspected.
Whole, motor-front, rear-stack, side and transparent-board encoder views are preserved
as viewer-*.png in revision 0.0.8 evidence. The viewer uses the actual current
native GLB, with no substituted electronics. Its transparency control was
fixed for the GLB's PCB group, then visually retested; no additional console
error occurred after that repair. It is an offline standalone HTML file.

The user's comparison image identifies HOLRY NEMA14 (35HBSG), a lead-screw
motor with 27/34 mm body lengths. That is a different model from the locked
Phidgets 3323_0 / 35STH40-1004B. NEMA 14 frame size alone does not establish
interchangeable rear geometry. The viewer now exposes the original motor front
and links directly to the official Phidgets ZIP. ZIP-member bytes match the
local STEP exactly; its plain appearance is the original simplified vendor CAD.
Download identity is confirmed; the 4.0/3.9 mm discrepancy still blocks fit approval.

Previous CadQuery inspection renders under previous-jst-orientation/ use
the earlier programmer orientation and are explicitly historical. Exact
measurements and assembly STEP were regenerated after the final connector
rotation; the current native viewer supplies the latest visual review.

## Collision evidence and remaining gates

The exact CAD checker imports all 29 distinct official supplier STEP URLs
for 57 components, and checks their actual circuit-JSON placement alongside
the original motor, PCB and proposed hardware. It reports 62 shape groups.
All pairwise positive-volume intersections and critical distances are saved
in ASSEMBLY-GEOMETRY-CHECK.json, linked to the native circuit SHA-256.

Unresolved USB C165948 model / PCB intersection: **0.358309 mm3**, B015.
Determine model/land/native placement registration before approving fit.
No hand-edited footprint or CAD compensation is allowed. Model contacts at
zero distance to the PCB are not positive-volume collisions. The intentional
modeled motor thread engagement is separately identified.

Measured nominal clearances include AS5600 to standoffs 2.223104 mm,
cup to standoffs 1.65 mm, magnet to standoffs 2.65 mm, magnet to PCB
3.5 mm, and AS5600 to unchanged STEP rear shaft tip 4.6 mm. These are
nominal CAD distances, not fully toleranced manufacturer acceptance.

Official native assembly build: zero generated error elements, no traces or
vias. Official placement DRC reports zero errors/warnings, after the seven actionable
orientation suggestions were fixed through native instance pcbRotation props.
This remains a diagnostic fixture, not qualification of the future routed layout. Existing imported symbol
and power/ground metadata warnings remain visible; none is suppressed or
accepted for fabrication. Functional schematic/BOM blockers remain.

**Mechanics has not passed.** Per the user's sequence, the next manufacturer
USB footprint audit remains gated. The existing B011 HRO/GCT land-pattern
discrepancies remain valid and neither connector is qualified for fabrication.
There is no routed copper, fabrication package, prototype test or order.

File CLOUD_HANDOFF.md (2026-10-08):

# Active routing — 0.0.53-alpha.0

Read `docs/REV53-LOGIC-POWER-ESCAPES.md`. The canonical native replay retains
all56/120 complete nets, with240 required opens,128 tracks,82 ordinary0.30/0.45mm
full through vias,five manifested TypeVII thermal vias and seven filled regions.
Native other-errors:0; unchanged strict and filled-copper clearance failures:0;
GND remains one physical network. Original purchased definitions, all165 fitted
model transforms, capacitor placement, motor and carrier are preserved.
The complete USB_VDD bypass/return geometry is screened; V3V3 remains incomplete.
Continue3.3V/core power,PD/eFuse controls,USB pair and ALL remaining physical nets.
Publication is WIP; loaded power/USB/thermal,complete CAM,quote and hardware tests
remain pending. Do not stop at this step. PROTOTYPE FABRICATION READY:NO.

---

# Active routing — 0.0.52-alpha.0

Read `docs/REV52-VM-POWER-ROUTING.md`. Qualified power019 joins56/120 required
nets, including every RAW/protected-VBUS/VM terminal and all prior54 nets.
265 opens,112 tracks,79 ordinary0.30/0.45mm full through vias,five manifested
TypeVII thermal vias,eight native filled regions. Native other-errors:0; strict
and filled-copper clearance failures:0; GND remains one physical network.
Keep all supplier imports/models/placement unchanged. Continue3.3V and core
power,PD/eFuse controls,USB pair with return path,then ALL remaining connections.
Accepted main routes are phase0; VM fanouts phase2; new selected-net routing
is phase3 so existing power copper is a frozen obstacle. Publication is WIP;
loaded power/USB/thermal,complete CAM,assembly quote and hardware tests pending.
Do not stop at this checkpoint. PROTOTYPE FABRICATION READY:NO. No board order.

---

# Active routing — 0.0.51-alpha.0

Read `docs/REV51-POWER-THERMAL-ROUTING.md` and the two-port architecture in
`docs/REV50-TWO-PORT-ROUTING.md`. Power059 joins54/120 required nets, including
all seven common PD-FET-source terminals, with291 opens,87 tracks,66 ordinary
0.30/0.45mm through vias,five explicitly manifested filled/capped U2 thermal
vias and six GND regions. Zero other native errors and zero unchanged strict
clearance violations. All previous53 complete nets remain physically joined.
Keep the original supplier footprint/pins/models. The five TypeVII vias require
selective filling/capping and CAM/quote confirmation; they are not ordinary open
via-in-pad holes. Continue protected VBUS/VM, then logic power, controls, USB pair
and ALL remaining required physical connections. Publish this checked step as
WIP and continue routing immediately. PROTOTYPE FABRICATION READY:NO.

---

# Active owner requirement — two USB-C ports / 15 V motor power

Current implementation, electrical interlock and routing evidence are in
`docs/REV50-TWO-PORT-ROUTING.md`. Read it before continuing. Finish raw/protected
VBUS and VM power first, then PD/eFuse controls, then USB data with its return
path, then all remaining required nets. Revision48 is historical;
exact publication status is recorded by the receipts in VALIDATION.md.

Revision0.0.50-alpha.0 continues the RP2040/STUSB4500/MCP2515 board. The latest
owner instruction requires separate USB-C motor PD POWER and COMPUTER DATA ports.
Motor power must prefer exactly15V (remove the active20V PDO in STUSB4500 NVM,
program/read back and document the procedure). Data-port5V must stay electrically
isolated from high-voltage PD VBUS and must never energize the motor. Verify
RP2040 data VBUS sensing, logic startup and hardware motor inhibition until a
valid15V contract. Use additional official imported parts and necessary connector
placement changes, retaining35x35mm4layers, motor and front carrier where possible.
Requalify electrical pin tables, exact models, actual assembly/cable/hole fit and
placement before dependent routing. Earlier one-port/four-connector freezes below
are historical and superseded only as needed for this two-port architecture.

The pre-change routing is preserved in evidence/rev-0.0.49-alpha.0/qualified-source
and routing/manual160:69/108 networks,102 source paths,92 ordinary0.30/0.45mm vias,
nine pours,217 opens,zero other native/strict errors,all69 includingGND physically
joined. Do not throw away unchanged qualified work or replay legacy STM32 copper.
Finish every required connection using one bounded nativePipeline9 job at a time
and supported manual source paths. No unchanged repetitive timeouts, generated
JSON edits, vendor patches, lowered DRC or substitute routers. Verify/install latest
released coherent tscircuit/CLI/core/router/converter with Bun lockfile. Preserve
all imports/models/evidence. Complete power/USB/thermal/freshCAM/stock/assemblyquote
gates and matching public GitHub/tscircuit source/JSON/CAD publication. Do not stop
at a partial checkpoint. PROTOTYPE FABRICATION READY:NO; no fabrication order.

---

# Active routing — 0.0.48-alpha.0

Read docs/REV48-ROUTING-CHECKPOINT.md, VALIDATION.md and the manufacturer review
in docs/REV45-PRE-ROUTING-REVIEW.md. The checked native replay connects64/108 nets:
97 tracks,79 ordinary0.30/0.45mm through vias,eight pours and227 open ports;
zero other native errors or strict copper violations. GND is one physical
network. Programmer/ADC/CAN select/interrupt routes are saved and manually
corrected. R_CAN_CS moves to bottom(1.5,-0.2), rotation0; C31 remains original.
Actual current CadQuery and mounted146-mesh review pass. Continue one bounded
selected-net native Pipeline9 job at a time; save qualified source paths and
manually correct actual DRC. All44 remaining nets, current/thermal/USB/fresh
CAM/assembly quote remain open. Preserve imports/models/history, exact motor,
connectors, outline and carrier. Publish completed checked prototype steps
with exact JSON/CAD bytes under standing authorization. FABRICATION READY: NO.

---

# Historical revision47 continuation

# Active routing — 0.0.47-alpha.0

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

---

# Historical revision46 continuation

# Active continuation — 0.0.46-alpha.0

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

---

# Historical revision45 handoff

# Active RP2040 / autonomous USB-PD continuation — revision45

Read root AGENTS.md, VALIDATION.md and docs/REV45-PRE-ROUTING-REVIEW.md.
The partial canonical build has44/108 physically joined nets,63 traces,
36 uniform0.30/0.45 ordinary through vias,7 pours and283 native open-port errors.
There are zero other native errors or strict copper violations in that partial
build; full connectivity and fabrication qualification remain incomplete.

All53 exact parts have fresh positive official JLCPCB stock/SMT checks.
Quote/allocation remain pending. All12 ICs /148 genuine STEP models pass actual
CadQuery checks. Ten moved USB/bypass/crystal parts pass renewed native placement
and actual mounted148-mesh nominal envelope clearance. The coherent latest
released tscircuit2750/CLI2254/core2105/Pipeline9 962 toolchain installs with
frozen Bun dependencies through the official registry mirror and normal TLS.

Keep routing one changed selected-net native job at a time until every net is
physically complete. Never replay STM32 copper or patch supplier definitions,
models, generated JSON, dependencies or checks. Preserve failed candidates.
The solved finer-mesh USB candidate is rejected for different inner layers,
self-short, skew and pad clearance; solver success is not qualification.
Prefer outer power, and finish isolatedEFUSE_RTN, ground, USB coupling/return,
loaded widths, thermal and fresh CAM/assembly review. The disclosed TVS style
finding must not stop independent PCB work. Keep the exact motor, outline,
four connectors and carrier. Publish completed prototype steps with exact
matching fresh JSON and original CAD bytes under the standing authorization.
PROTOTYPE FABRICATION READY: NO. No order is authorized.

---

# Historical redesign — 0.0.44-alpha.0

User requested RP2040 and actual dedicated USB-PD plus all review corrections.
U1 is C2040 with flash/crystal; U3 is C2678061 STUSB4500 with genuine C222138
back-to-back PMOS switches. MCP2515 restores classic CAN via SPI1. TMP112 and
functional buzzer now share a populated I2C sheet. All147 references have notes.
See docs/RP2040-USB-PD-REDESIGN.md and current VALIDATION.md.

The canonical board is UNROUTED: 0 traces/vias/pours, 108 required nets and
504 explicit native unconnected-port errors. Zero placement errors does not
mean connected copper. Default native routing is disabled. Legacy STM32 saved
paths fail explicitly if enabled; preserve them historically, never replay.
Ordinary future vias use0.30/0.45 mm with via-in-pad disabled. Outer power,
thermal/USB/CAM/assembly qualification must restart on this architecture.

Exact motor, four connectors, outline, four layers and front carrier remain.
Original models/imports/route modules/evidence are preserved. The previous
context manifest is archived in evidence/rev-0.0.44-alpha.0. Factory PD profiles
and firmware safeguards are documented; no physical negotiation/flashing claim.
Latest dependency install requires blocked pkg.pr.new; manufacturer hosts
also require activating the saved environment draft. No substitute or bypass.
PROTOTYPE FABRICATION READY: NO. No fabrication order authorized.

All handoffs below describe historical revisions.

---

# Current continuation — 0.0.43-alpha.0

All 158 previous 0.30/0.60 mm vias now use 0.30/0.45 mm through native source.
The other 66 small filled/capped vias remain and need relocation/rerouting;
uniform sizing is incomplete. Independent spacing rules and exact filled owners
are preserved. Purchased wiring, wire geometry, official imports and CAD stay
unchanged. Fresh native build and current qualification records are in
VALIDATION.md and docs/VIA-POWER-BUZZER.md. 327 traces/224 through vias/82 pours,
all82 physical nets joined, zero native errors or strict copper violations.

VM/input VBUS wires are outer; four motor nets and part of3.3 V still use inner
wires. The new bottom3.3 V trial shorts and the corrected outer-only Pipeline9
job hits its8 GiB guard. No trial power route is adopted. Existing U9 TMP112
provides I2C temperature sensing like the reference RP2040 board. Buzzer placement
is diagnostic only; official datasheet host access and a complete qualified
driver/circuit/mechanical/routing addition remain pending. All sourcing, thermal,
fabrication, firmware and hardware blockers remain. Preserve the80 original
model files and all current Circuit JSON mirrors.
**PROTOTYPE FABRICATION READY: NO.** No fabrication order is authorized.

---

# Current continuation — 0.0.42-alpha.0

Ten full-analyzer schematic findings are corrected through native layout.
One imported D_VBUS rotation issue remains; the unchanged official React symbol
ignores rotation in the installed runtime. Read docs/SCHEMATIC-STYLE.md and
VALIDATION.md. Exact purchased wiring, all PCB records and CAD remain unchanged
from0.0.41; fresh native JSON, strict geometry/filled nets and CAM vector checks
pass.327 traces/224 through vias/82 pours; all82 nets joined, zero native or
strict copper errors. Preserve all official imports, local models and saved routes.
All fabrication/sourcing/thermal/firmware/hardware blockers remain disclosed.
**PROTOTYPE FABRICATION READY: NO.** No fabrication order is authorized.

---

# Current continuation — 0.0.41-alpha.0

User selected official TMC2209-LA-T C2150710 and TI TPD2EUSB30DRTR C97502.
The exact supplier imports are unmodified; manufacturer tables and raw pads
are verified. All 411 electrical pin partitions, placements, copper, pad/drill/
silk geometry and CAD registrations/model bytes remain exact. U1 is unchanged
and lacks a verified stocked drop-in. Q_PD is unchanged: the later exact
official JLC shop lookup lists genuine ST C2965326 with 100 units and presale 97
(2026-10-06); stock allocation and assembler acceptance remain unverified.
See docs/FABRICATION-REVIEW.md for the latest review. The USB part has a higher
stand-off/breakdown threshold and needs system ESD/USB hardware qualification.
Fresh native minimum runtime build and applicable automated screens pass;
all 82 nets connect, with 327 traces/224 vias/82 pours and zero native/strict
copper errors. Preserve every original import, saved route and historical file.
Read VALIDATION.md and docs/PART-REPLACEMENTS.md for exact results and blockers.
**PROTOTYPE FABRICATION READY: NO.** No fabrication order is authorized.

---

# Current continuation — 0.0.40-alpha.0

U4 AS5600 and C6 removed by user request. Keep R2/R3: U9 TMP112 still uses I2C.
Read docs/ENCODER-REMOVAL.md and current VALIDATION.md. Shared supply and bus trees
are reconnected at remaining pads; the central GND return is retained. Fresh
native copper has327 traces,224 through vias,82 pours,zero errors,82/82 joined
nets and zero strict geometry violations. Programmer wiring checks pass.
Existing qualification blockers and untested hardware remain.
**PROTOTYPE FABRICATION READY: NO.** Preserve unused official imports/models and
historical evidence; they do not instantiate the removed parts in the board.

---

# Schematic component explanations — 0.0.38-alpha.0

All 111 electronic references now have native schematic purpose notes on their
nine A4 sheets. Drawing coordinates and prose were reflowed for readable panels;
electrical connections, all PCB geometry, supplier imports and CAD are unchanged
from revision 0.0.37. Read current VALIDATION.md and evidence/rev-0.0.38-alpha.0/.
**PROTOTYPE FABRICATION READY: NO.** Existing ordering blockers remain.

---

# Current manual fixes — 0.0.37-alpha.0

The native Gerber ground mismatch is resolved by moving the exactly owned C25
ground escape 0.13 mm in source. All four board-owned connector labels now pass
native CAM mask/width/outline measurements. All 82 nets remain connected, with
zero native errors/shorts and zero strict copper violations. Supplier outlines,
four orientation metadata gaps, sourcing, power/thermal and fabrication-process
qualification remain open. Read current VALIDATION.md, docs/EXPORT-BLOCKERS.md
and evidence/rev-0.0.37-alpha.0/. Preserve every official import and model asset.
**PROTOTYPE FABRICATION READY: NO.** No order authorized.

---

# Latest continuation — 0.0.36-alpha.0

The released tscircuit toolchain and motor/CC1/CAN_RS copper fixes are complete;
100 Ω official programmer resistors are fitted in source. All 82 native copper
networks are connected. Read the current VALIDATION.md, docs/BOARD-REVIEW.md and
evidence/rev-0.0.36-alpha.0 before using the older handoff below. Build the minimal
runtime packet from its own root to preserve ./imports CAD URLs. All models must
be included and verified at publication; do not modify generated Circuit JSON.

The board is still **not ready to order**: native Gerber GND mismatch, supplier
silkscreen clearance/width, four supplier rotations, stock allocation and complete
power/via/thermal/fabrication-process review remain open. Physical tests and
firmware are absent. Preserve all original supplier modules, model assets,
mechanical references and reviewed small-via owners. No fabrication order is
authorized.

---

# Smart NEMA 14 controller: complete Cloud handoff

## Six-point board review — 2026-10-06

See docs/BOARD-REVIEW.md and docs/PROGRAMMING.md. Design sources, imported parts,
placement, saved copper and canonical SHA
`63076b482262db351ea8136616baf8afc8594d505a2a0932eb0c336d29395f53` are unchanged.
Exact canonical checks again pass: 82/82 physical nets, zero unintended opens or
shorts, zero strict copper/filled-pour violations, native placement zero errors
and warnings, native runtime netlist zero errors and warnings, 38 programmer
pin/net assertions passed. Native pin-specification retains 27 metadata warnings.

**The nominal motor-width pass below is not a manufacturing-tolerance pass.**
The now-reachable official JLCPCB capabilities page specifies ±20% track-width
tolerance. Applying it to the retained peak-current/30 C screen fails 26 internal
motor segments across all four phases: minimum .310431/.329776 A vs .342448 A.
Current width qualification is blocked. All 43 exact parts were queried in both
the indexed catalogue and official public Parts Library; four fitted codes
C2847904/C465949/C94934/C2965326 have no exact public in-stock result. Pre-order
results differ and actual assembler allocation is unconfirmed. Programmer J3
five-pin order matches, VOUT remains unconnected, and target needs its own USB-C
supply. Its 1 kilohm series resistors/TMUX require timing qualification versus
the official recommended 100 ohms. Final CAM/orientation/silkscreen and full
power/via/thermal/transient review remain unfinished.

**PROTOTYPE FABRICATION READY: NO. Hardware and programming untested; firmware
not delivered; no fabrication order placed.** This is a review metadata update
for revision 0.0.35-alpha.0, not a new electrical/copper revision. Exact review
checks and official source snapshots are in
evidence/rev-0.0.35-alpha.0/board-review-20261006/.

## Current Linux continuation — 0.0.35-alpha.0, 2026-10-06

Routing is complete using supported native source paths. Fresh full CLI build
passes with **334 traces, 224 vias, 82 pours and zero native errors**. All 82
physical nets have one connected copper component, with zero foreign-pour
spacing violations. Strict copper/drill/edge/NPTH checks pass with all 68 exact
filled-feature owners matched; native shorts reports none. All 421 purchased
pins retain their complete named and unnamed wiring partitions. The independent
fresh schematic-only manufacturer-pin tests pass for 111 supplier references,
nine sheets, programming/protection connections and current-limit values.

Canonical SHA-256: `63076b482262db351ea8136616baf8afc8594d505a2a0932eb0c336d29395f53`.
All three committed JSON mirrors match this fresh CLI output. Original 111
placements, 423 pads, 195 prior barrels and 51 prior owned features are preserved;
four local saved paths change to open verified corridors. Added ground and RTN
reconnections repair actual islands without joining EFUSE_RTN to GND. All
physical PCB geometry is exact across the final default-DNP metadata update.
U4/C6/R50 use supported doNotPlace props; their copper remains present, while
BOM/CPL correctly exclude those three references.

All 2,209 nonzero wire segments across 82 nets are inventoried. Width floor
and motor phase-current screens pass; the narrowest internal motor section is
0.23 mm, screened at 0.36494 A versus the conservative 0.34245 A phase peak.
Inner sections of 0.25 mm screen at 0.38768 A. These assume the recorded copper
thickness and 30 C rise model. Thirty native width warnings remain: a combined
same-net tree's minimum is compared with individual .18/.20/.28/.40/.60 mm
requests. All 34 active fanout corridors are covered at their requested widths (POWER-FANOUT-WIDTH-REVIEW.json). No warning is suppressed. Actual loaded power paths, pours/necks,
parallel paths, via plating, switching loops and thermal spreading are not yet
fully qualified. RAW VBUS's previously measured 1.455 mm neck screen remains
applicable because its physical copper is unchanged. Power tolerance/regeneration
corner screens pass their stated bounds; high-frequency transients remain open.

Fresh USB paths measure DP 25.13552 mm, DM 24.75408 mm, skew 0.38144 mm (<0.5).
Adjacent ground covers the signal core. The approximate 91.812 ohm result uses
the selected nominal stackup, not a field solver or confirmed fabrication coupon.
The four copper-layer images were viewed before the DNP metadata-only change;
physical silkscreen is unchanged and still crowded, with some labels outside
outline. Cosmetic D_VBUS schematic rotation and imported metadata warnings remain.

Direct native tscircuit Gerbers/drill/BOM/CPL export passes identity checks:
224 plated drill hits, six NPTH, no duplicate hits, exact supplier identities,
positions/layers and 108 default fitted references. Four supplier orientations
remain unverified: J_USB, LED_POWER, LED_STATUS and LED_FAULT. Complete Gerber
copper/outline/mask/paste review and assembler feedback remain pending. The old
KiCad conversion reported 2,023 violations and 55 disconnected export items,
including duplicate objects and mismatched default rules. Its failures are
retained, not disabled or described as an approved fabrication export.

All local model dependencies remain present. Actual assembly/mounted previews
build, and the nominal exact-motor/front-carrier BRep/AABB audit passes for all
111 references. The carrier/tolerance and constrained mating-envelope analytical screens also
pass; the limiting J_IO clearance is .1643 mm after allowances. Actual
physical assembly and mating fit remain untested. The live catalogue check passes all 43 exact parts with displayed
stock; that does not reserve stock. TypeScript and formatting pass.

Evidence: evidence/rev-0.0.35-alpha.0/, especially cloud/canonical-population/,
TRACE-WIDTH-AUDIT.json, PIN-PARTITION-PRESERVATION.json and NATIVE-CAM-AUDIT.json.
Rejected routing experiments are losslessly archived with per-file SHA-256;
accepted canonical evidence remains unpacked. The runnable package excludes
historical routing/debug trials but retains necessary sources, imports, models,
pinned dependencies, checks and fresh Circuit JSON. Existing historical evidence,
official references, context manifests and .agents/skills/tscircuit are preserved.

Cloud currently denies CONNECT access to jlcpcb.com for its official capability
page. An additive draft preserves the known dependency/supplier hosts and adds
jlcpcb.com. Saving a draft does not apply or publish policy; review/save and
Publish are environment-panel actions, followed by an actual request retry.
Manufacturer confirmation of the .15/.20 mm named TypeVII filled/capped process,
minimum copper/plating and exact stackup remains an ordering blocker.

Revision035 publication is verified: public GitHub source/artifact commit
`9c5b63415baad275a9d045c535696ab3884c56bf` and public tscircuit release
`18fcb173-e240-4c1b-aa98-6a5f83fef3d3`. All 384 runtime package files and
13 GitHub source/artifact files passed anonymous SHA-256 readback,
including all three canonical JSON copies and every unchanged model asset.
PUBLICATION.json identifies that exact snapshot. Subsequent metadata receipts
record only documentation/review updates; routed source and JSON remain exact. No hosted build success is
claimed. Stages 4/5/6 are incomplete; firmware and hardware tests are pending.
**PROTOTYPE FABRICATION READY: NO.** Do not order from this review packet.

CAD publication repair (2026-10-06): all 111 CAD entries retain their model
references and all 82 unique local dependencies exist in Git. The earlier
selected publication packet omitted every referenced local OBJ/STEP/STP asset;
this caused missing models in the public package despite intact supplier imports.
All 105 existing model assets (including imported models, exact USB/eFuse models
and the official motor STEP) are now restored and anonymously verified byte for
byte. The motor STEP needs binary upload to preserve its non-UTF8 encoding.
The remaining remote SWD connector OBJ/STEP URLs both return HTTP 200 and valid
model bodies. A new publication coverage guard rejects the old packet with
82 omissions and passes the actual repaired public inventory with zero omissions.
Circuit/source geometry and all three canonical JSON hashes remain unchanged.
See evidence/rev-0.0.34-alpha.0/cad-publication/ for manifests,
before/after audits and asset readback. The hosted rebuild remains pending.
Hosted 3D rendering and assembled fit remain separately unverified.

## Historical Linux continuation — 0.0.34-alpha.0

SWDIO_GUARDED physically joins U7 pin3 and R20 pin1 through a supported
native source tree. The old POWER_GOOD barrel obstructed the U7 outlet:
0.2258 mm surface gap cannot fit the 0.15 mm signal plus required pad/via
clearance. That ordinary barrel moves to (7,-12.85), retaining dimensions,
full span and masks. One exact-owned TypeVII filled/capped ENIG U7 escape
(.20/.38 mm) and one ordinary .30/.60 mm R20 barrel complete the link.

All 156 other saved paths and all existing explicit pours remain exact.
All 268 other net/layer copper groups remain within 0.1 nm; all 192 other
prior barrels preserve drill, pad, full span and effective tenting. All 421
component pin-net assignments remain exact. The manufacturing manifest has
51 individually declared features, with no blanket exception. Actual native
Pipeline9 input covers all 195 current annuli on all four layers and retains
.30/.60 mm ordinary new-via minima. The board wrapper now consistently selects
the requested beta_pipeline9 even when a seed job has no target list.

Fresh full build: **238 traces / 195 vias / 74 pours**, **9 native unconnected
ports + 6 unfinished trace errors**, **75/82 physical nets complete**.
Canonical SHA-256: `519f8e29e54829445772ef4dec82ef712788d259f3556068d92bd160ce4cc855`.
Strict geometry and foreign filled-copper clearance have zero violations.
Native netlist/shorts/schematic placement, TypeScript, formatting and imports
pass. After successful network verification, the fresh full CLI build completed
in 45.045 seconds with 7255.5 MiB peak sampled RSS. Its element serialization
changed, but all 276 emitted net/layer copper groups preserve geometry within
0.1 nm, all 195 barrel dimensions/spans/effective masks remain exact and all
74 emitted pours remain byte-exact. See cloud/canonical-after-network-verification/
EMITTED-ALL-COPPER-PRESERVATION.json and REBUILD-PRESERVATION.json. All six power/reference networks remain joined and EFUSE_RTN isolated;
USB reference/skew and RAW-neck analytical screens pass. All four current layer
images were actually viewed. Crowded silkscreen and bottom labels at/outside
outline remain. Build/all-net checks correctly exit 1 for retained errors.

Native Pipeline9 seeded controls exhausted iterations at port pathing after
833.624 s / 12904.469 MiB, with no route adopted. A changed SWCLK-only seed job
hit the guard after 743.678 s / 23477.973 MiB at available-segment point solving.
Its seed output is not a completed Pipeline9 result. An earlier wrapper-selected
Pipeline7 seed run was stopped at 43.063 s and rejected; the wrapper is fixed.
A supported endpoint-pair trial created no native phase1 because of inferred net
ownership; it is removed. A manually proposed eFuse fault trunk passed spacing
but split RTN and interrupted USB reference, so its source is reverted. Rejected
trials and exact source snapshots remain evidence, with no checks disabled.
The unseeded POWER_HIGH_CURRENT-only Pipeline9 job timed out after 901.315 s
with 13607.754 MiB peak sampled RSS in edge solving (0.28). No output was adopted.
The invalid eFuse seed is removed from active helpers; exact rejected source
remains archived.
A changed two-real-pad-root POWER_HIGH_CURRENT seed still timed out after
901.447 s / 13132.152 MiB in edge solving. All 195 annuli remained covered in
its actual input. No final route exists. The six-contact experimental extension
is reverted to the fourteen-file pre-trial source snapshot matching the
successful final CLI build; source restoration is checksum verified. The core
diagnostic is retained separately and lacks CLI supplier pin-one metadata; it
is not accepted as a replacement build.

A changed official Pipeline9 SDK attempt forwards that exact 7655-obstacle,
two-real-pad-root input unchanged and uses public mesh options dimension3/ratio30
instead of dimension15/ratio6, retaining minNodeArea .01, effort1 and every
manufacturing constraint. It passes edge solving (68894 regions, 211696 edges),
then times out in portPointPathingSolver after 901.305 s / 21262.180 MiB peak
sampled RSS. No final route exists and no board source/copper is adopted.
The installed official class and pinned dependencies remain intact. Exact input
provenance, source snapshot, progress, guard result and reproduction instructions
are in cloud/power-high-mesh-native9-001/. Explicit source-access alternatives
also violate actual pad/trace/via clearances and are rejected. This is a native
routing performance blocker, not a package-network or setup failure; these
unchanged jobs must not be repeated. An official native improvement or a changed
source plan is required before the seven nets and fabrication gates can finish.
The exact failure/reproduction packet and unchanged three canonical mirrors
are publicly verified at GitHub commit `556d29bfc95f579731448c626d3691d33bbc57bb`
and the existing revision34 release: all 30 updated files and six key GitHub
files passed anonymous checksum readback. See PUBLICATION-PIPELINE9.json.
The registry's unversioned download endpoint caches for 24 hours; its anonymous
file API and checksum-addressed downloads return the current verified bytes.

Exact saved Cloud startup smoke passes: TypeScript, critical import labels,
pinned Linux analysis libraries, complete context inventory and four archive
parts. Source/format checks pass. Actual cgroup RAM is 32 GiB, swap is zero,
and workspace disk has 27.58 GiB free out of 31.45 GiB.

The base publication matches public source/artifact commit
`169b518f865632e9b97b61bb34603463d829ce6a` and tscircuit release
`1f1e413e-9f44-43c5-8c58-e97d64e38a75`: all 386 base package files and
13 key GitHub files passed anonymous SHA-256 readback. PUBLICATION.json records
that initial snapshot. The subsequent network-verified rebuild above changes
serialization only; its current artifact/metadata readback is recorded separately
in PUBLICATION-METADATA.json: all 47 updated files and six key GitHub files
passed anonymous checksum readback at commit
`76c5a75a0758ff55a37b4cf3b488838ced28d6f1`.

Seven physical nets (TMC_DIR, SWCLK, EXT_STEP_CONN, EXT_DIR, CAN_RS,
EFUSE_FLT_N, POWER_HIGH_CURRENT) and full power/via/thermal/transient,
signal, USB/SI, 3D/mechanical and CAM gates remain unfinished. Live official
EasyEDA product responses match all 43 unique supplier identities for 111
references. The official CLI catalogue check now passes all 43 exact parts
with nonzero displayed stock; the exact model URL with its official UUID
returns HTTP 200 and a real OBJ. Both formerly denied hosts now permit these
requests. Node fetch tools use supported NODE_USE_ENV_PROXY=1. The 14-host
draft is saved; successful actual requests do not prove draft publication,
stock reservation or final 3D fit. Earlier 180/360-second failed builds are
rejected, with no stale output accepted. Firmware and hardware tests remain
unperformed; no hosted build success is claimed.
**PROTOTYPE FABRICATION READY: NO.** Continue all TASK.md nets and qualification.

## Historical Linux continuation — 0.0.33-alpha.0

TMC_ENABLE_N now physically joins U1 pin15, U2 pin2 and R7 pin2 through the
corrected native three-layer tree and two ordinary 0.30/0.60 mm through vias.
The route initially split the VM plane at C14. A reviewed inner1 native pour
reconnects C14 to the eFuse output, with a local bulge around the USB NPTH; all
six power/reference networks remain joined and EFUSE_RTN stays isolated.

All 151 previous saved paths and 20 explicit pours remain exact. All 265 other
net/layer copper groups stay within a 0.1 nm serialization envelope. All 191
prior via drills, pads, spans and effective tenting flags are preserved; 421
purchased/component pin-net assignments stay exact. Saved paths now walk each
through barrel fully for native obstacle coverage. The active USB ESD GND via
is explicitly 0.30/0.60 mm. Actual Pipeline9 input covers all 193 current via
annuli on all four layers. Two retained filled contacts preserve original
mask settings; all 50 manufacturing declarations remain unchanged.

Fresh official full build: **234 traces / 193 vias / 74 pours**, **11 native
unconnected-port + 6 unfinished trace errors**, **74/82 complete physical nets**.
Canonical SHA-256: `2a308b0c3d2d0ae50ffbd2d748f8f3365f8d842b7184a0b7d36037e1eca26534`.
Strict geometry, foreign fill clearance, native netlist/shorts/schematic placement,
TypeScript, imports and formatting pass. USB return/skew and RAW-neck analytical
screens pass. Full build exits 1 for retained errors; all-net filled review
exits 1 for eight incomplete nets. All four current layer renders were actually
viewed. Crowded silkscreen and bottom labels at/outside outline remain.

Historical Pipeline4 output seeded the corrected enable route but its raw result
failed geometry/power and was not adopted. The VM Pipeline4 run was stopped
when the user selected Pipeline9. VM Pipeline9 timed out at 901.397 seconds,
15,756.520 MiB peak, in joint DRC repair (0.84), with no final route adopted.
All future remaining-net jobs use native beta_pipeline9 only. Rejected source
trials and stale output are explicitly identified in ARCHIVE-PROVENANCE.json;
no check was disabled and no generated JSON or imported component was patched.
See TMC-ENABLE-ADOPTION.json and cloud/canonical/CHECKS.json.

Public revision0.0.33 matches source/artifact commit `642bfbe516b4ac4cbbc0bd00e2f876b07afe537f` and release `20809bda-8414-4ea2-aef8-c7f4c6754ed2`: all 326 base package files and 13 key GitHub files passed anonymous SHA-256 readback. Exact Cloud smoke and 4311 context files plus all four historical archive parts were verified. No hosted build success is claimed. Eight physical nets and
full power/via/thermal/transient, USB/SI, signal, 3D/mechanical and CAM gates
remain unfinished. Live official supplier verification still needs easyeda.com
runtime policy activation through the environment editor. Firmware and hardware
tests are unperformed; no hosted build success is claimed.
**PROTOTYPE FABRICATION READY: NO.** Continue all TASK.md nets and qualification.

## Historical Linux continuation — 0.0.32-alpha.0

The four motor phase routes had 0.15 mm internal sections, below the conservative
0.34245 A phase bound in the IPC-2221 / 30°C analytical screen. Native source
repairs now use 0.25 mm internally, with one 0.23 mm MOTOR_A2 corridor segment.
Screened capacities are 0.38768 A and 0.36494 A. Minimum manufactured copper,
barrel plating, thermal and transient qualification remain pending.

Existing saved trunks are represented as real-port native trees. All 253
unchanged net/layer copper groups are preserved within a 0.1 nm numerical
serialization envelope. All 38 V3V3 declarations stay exact; all 48 earlier
owned filled features stay exact. Two individually owned filled contacts and
a native driver/pullup branch reduce TMC_ENABLE_N to two physical groups.
Direct native links now use resolved start-port selectors so the router treats
them as fixed. A numeric-zero-start trial changed four links and failed actual
geometry/shorts; it is rejected and retained separately.

Fresh official full build: **227 traces / 191 vias / 73 pours**, **11 native
unconnected-port + 7 unfinished trace errors**, **73/82 complete physical nets**.
Canonical SHA-256: `dd2cda6ddc62e20f50703db7bb7487df47b862a56c9f41dc516f5c0678872bd1`.
Strict geometry, foreign fill clearance, native netlist/shorts/schematic placement,
TypeScript, imports and formatting pass. All six power/reference networks are
joined and EFUSE_RTN stays isolated. USB reference/skew and RAW-neck analytical
screens pass. Full build exits 1 for retained unresolved errors. All four current
layer images were actually viewed; crowded silkscreen and bottom labels at/outside
the outline remain. Supplier imports, connector placement and mechanics remain
intact. Unchanged manufacturer schematic evidence is reused from revision23.

The earlier access-only driver-enable Pipeline9 attempt was manually stopped
at 1583.226 seconds / 13599.328 MiB peak after edgeSolver stalled; no route was
adopted. The changed compacted/fixed source is eligible for a fresh bounded job.
Optional CLI path-cache serialization still reports a nonunique imported-port
selector; fresh native JSON exists and electrical/import checks pass. Prior
revisions had the same class of cache warning; imports were not patched.
Evidence: POWER-ACCESS-ADOPTION.json and cloud/canonical/CHECKS.json.
Matching public publication is verified: source commit `3c732b1468958add4ffd1e450dab483231eaefc9`, release `29149b5a-7ffd-4c73-8c7d-fa39be2b45d2`, all 314 base files and eight key GitHub files matched anonymous SHA-256 readback. Exact Cloud smoke passed; all 3933 context files and four historical archive parts verified. No hosted build success is claimed. Live official supplier
verification needs the saved easyeda.com policy applied through the environment
editor. Nine nets and full power/USB/signal/3D/CAM gates remain unfinished.
Firmware and hardware tests are unperformed; no hosted build success is claimed.
**PROTOTYPE FABRICATION READY: NO.** Continue all TASK.md nets and qualification.

## Historical Linux continuation — 0.0.31-alpha.0

LIMIT1 is physically complete between U1 pin 22, C30 pin 1, R26 pin 2 and R31 pin 2.
The complete native saved star uses inner1, both existing ordinary MCU/cap
escapes and the existing filled filter contact. All 148 earlier saved paths
and all 48 individually owned filled features remain exact. No new vias,
imports, placement, wiring, dependencies or mechanical changes were made.

Fresh full official CLI build: **224 traces / 189 vias / 72 pours**, **14 native
unconnected-port + 6 unfinished trace errors**, **73/82 complete physical nets**.
Canonical SHA-256: `04ba8d990851f101e528d95831c468a3dcb7176b75b184141058bafee406e8a5`.
Strict geometry, foreign fill clearance, source netlist, native shorts, imports,
TypeScript and formatting pass. All six power/reference networks stay joined;
EFUSE_RTN remains isolated from GND. USB reference/skew and RAW-neck analytical
screens pass. Full build exits 1 for retained errors. The unchanged manufacturer
pin schematic-only test reuses 0.0.23 evidence. Cosmetic D_VBUS styling remains.
All four current layer images were actually viewed; crowded silkscreen and
bottom labels near/outside the outline remain. Nine physical nets and complete
power/via/thermal/transient, USB, signal, 3D/mechanical and CAM qualification
remain pending. Firmware and hardware tests are unperformed.

LIMIT1 trial001 omitted its fourth logical endpoint, so native saved-phase
validation rejected it. Trial002 explicitly includes R31 pin 2. Native driver
DIR Pipeline9 timed out at 600.907 seconds in edgeSolver (progress 0.28), with
13146.85 MiB peak sampled RSS and no final output; no route was adopted.
Evidence: LIMIT1-ADOPTION.json and cloud/canonical/CHECKS.json.
Cloud resources and exact smoke results are retained. Live supplier availability
still requires runtime activation of the saved easyeda.com host draft and a
successful official request. Public revision 0.0.31 matches source/artifact commit `b3a748f2c3d6a979ea9088ba172069f49cbae59e`
and tscircuit release `6868a1c3-d5f1-49e7-a4e1-8e70d3c3e9ee`: all 311 package files
and eight GitHub files passed anonymous SHA-256 readback. Hosted build success
is not claimed. See PUBLICATION.json.
**PROTOTYPE FABRICATION READY: NO.** Continue all remaining TASK.md nets and gates.
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

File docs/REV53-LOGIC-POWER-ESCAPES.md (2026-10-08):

# Revision 0.0.53: USB supply escape and local logic branches

The canonical source replay matches the qualified logic022 trial exactly:
56/120 complete physical nets,240 required open ports,128 tracks,82 ordinary
0.30/0.45mm four-layer through vias,five unchanged TypeVII thermal vias and
seven native filled regions. All previous56 complete nets survive. Native
errors other than opens,unchanged strict copper/drill/contact violations and
filled-copper clearance failures are zero. GND is one physical network.
All four actual trial layers were viewed. Final loaded and manufacturing
qualification remains incomplete; this publication is a WIP prototype.

The original C_USBPHY position/rotation and original(8.3,7.7)GND stitch remain.
Supported board-owned paths repair QSPI_IO2's top approach and move QSPI_IO3
onto inner2 with two ordinary through vias, preserving the inner1 reference.
The complete ordered protected-VBUS subtree is retained; only the220kohm R16
auxiliary-discharge branch moves onto inner2. Its15.75V/1% corner is below73uA.
Original QSPI clock, all VM fanouts, supplier definitions and electronic model
transforms are unchanged. No generated Circuit JSON or vendor edits.

Sixteen explicit native local V3V3 traces include a0.18mm top USB_VDD bypass,
a0.18mm USB_VDD-to-IOVDD1 tie,a0.15mm low-current branch and thirteen0.35mm
local power branches. U1 pin48 is USB_VDD; pin49 is IOVDD1. The complete bypass
path is1.6603mm between pad centres,of which0.8815mm is outside the actual lands,
with zero supply vias. Its full exposed0.18mm copper strip has actual inner1
GND beneath it. A0.15mm top GND corridor joins the capacitor's ground pad to
its original via,0.7815mm away. A0.1989mm reference gap lies wholly beneath
the USB_VDD solder land; it is measured and disclosed,not a full-path plane
coverage claim. This is a geometry screen,not a field solver or transient test.
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

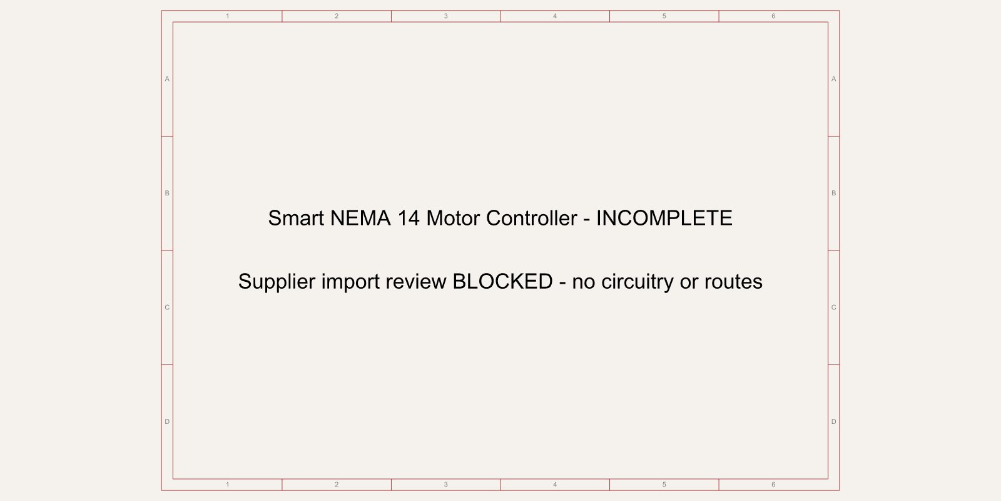
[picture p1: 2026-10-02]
evidence/schematic-envelope.png

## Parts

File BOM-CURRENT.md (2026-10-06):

# Complete candidate BOM — 0.0.43-alpha.0

109 references / 108 default fitted / 43 exact identities. Design-review BOM, not an assembly or fabrication approval. Stock is the CLI catalogue's indexed display, not an assembler reservation. Manufacturer identity is retained from the previously audited raw supplier record; MPN, package and classification are checked against the current exact catalogue match. Missing exact datasheet reviews remain explicit.

| Ref | Function / connected nets | Manufacturer | MPN | Package | JLCPCB/LCSC | Class | Datasheet/reference | Notes |
| --- | --- | --- | --- | --- | --- | --- | --- | --- |
| C1 | MCU: V3V3, GND | SAMSUNG(三星) | CL05B104KO5NNNC | 0402 | C1525 | Basic | [Supplier listing](https://www.lcsc.com/product-detail/C1525.html); exact datasheet qualification pending | Default fitted; ratings/DFM review pending; indexed stock 16407331 checked 2026-10-06T21:20:03.706Z |
| C2 | MCU: V3V3, GND | SAMSUNG(三星) | CL05A475MP5NRNC | 0402 | C23733 | Basic | [Supplier listing](https://www.lcsc.com/product-detail/C23733.html); exact datasheet qualification pending | Default fitted; ratings/DFM review pending; indexed stock 964426 checked 2026-10-06T21:20:03.652Z |
| C3 | MCU: V3V3, GND | SAMSUNG(三星) | CL05B104KO5NNNC | 0402 | C1525 | Basic | [Supplier listing](https://www.lcsc.com/product-detail/C1525.html); exact datasheet qualification pending | Default fitted; ratings/DFM review pending; indexed stock 16407331 checked 2026-10-06T21:20:03.706Z |
| C4 | MCU: V3V3, GND | SAMSUNG(三星) | CL05B104KO5NNNC | 0402 | C1525 | Basic | [Supplier listing](https://www.lcsc.com/product-detail/C1525.html); exact datasheet qualification pending | Default fitted; ratings/DFM review pending; indexed stock 16407331 checked 2026-10-06T21:20:03.706Z |
| C5 | MCU: NRST, GND | SAMSUNG(三星) | CL05B104KO5NNNC | 0402 | C1525 | Basic | [Supplier listing](https://www.lcsc.com/product-detail/C1525.html); exact datasheet qualification pending | Default fitted; ratings/DFM review pending; indexed stock 16407331 checked 2026-10-06T21:20:03.706Z |
| C7 | CAN: V3V3, GND | SAMSUNG(三星) | CL05B104KO5NNNC | 0402 | C1525 | Basic | [Supplier listing](https://www.lcsc.com/product-detail/C1525.html); exact datasheet qualification pending | Default fitted; ratings/DFM review pending; indexed stock 16407331 checked 2026-10-06T21:20:03.706Z |
| C8 | LogicPower: VM, GND | SAMSUNG(三星) | CL31A106KBHNNNE | 1206 | C13585 | Basic | [Supplier listing](https://www.lcsc.com/product-detail/C13585.html); exact datasheet qualification pending | Default fitted; ratings/DFM review pending; indexed stock 1877266 checked 2026-10-06T21:20:03.802Z |
| C9 | LogicPower: VM, GND | YAGEO(国巨) | CC0603KRX7R9BB104 | 0603 | C14663 | Basic | [Supplier listing](https://www.lcsc.com/product-detail/C14663.html); exact datasheet qualification pending | Default fitted; ratings/DFM review pending; indexed stock 12618106 checked 2026-10-06T21:20:03.578Z |
| C10 | LogicPower: BUCK_BST, BUCK_SW | YAGEO(国巨) | CC0603KRX7R9BB104 | 0603 | C14663 | Basic | [Supplier listing](https://www.lcsc.com/product-detail/C14663.html); exact datasheet qualification pending | Default fitted; ratings/DFM review pending; indexed stock 12618106 checked 2026-10-06T21:20:03.578Z |
| C11 | LogicPower: V3V3, GND | SAMSUNG(三星) | CL21A226MAQNNNE | 0805 | C45783 | Basic | [Supplier listing](https://www.lcsc.com/product-detail/C45783.html); exact datasheet qualification pending | Default fitted; ratings/DFM review pending; indexed stock 1734789 checked 2026-10-06T21:20:03.706Z |
| C12 | LogicPower: GND, V3V3 | SAMSUNG(三星) | CL21A226MAQNNNE | 0805 | C45783 | Basic | [Supplier listing](https://www.lcsc.com/product-detail/C45783.html); exact datasheet qualification pending | Default fitted; ratings/DFM review pending; indexed stock 1734789 checked 2026-10-06T21:20:03.706Z |
| C13 | MotorDriver: TMC_CPO, TMC_CPI | SAMSUNG(三星) | CL05B223KB5VPNC | 0402 | C307335 | Extended | [Supplier listing](https://www.lcsc.com/product-detail/C307335.html); exact datasheet qualification pending | Default fitted; ratings/DFM review pending; indexed stock 124 checked 2026-10-06T21:20:03.739Z |
| C14 | MotorDriver: VM, TMC_VCP | YAGEO(国巨) | CC0603KRX7R9BB104 | 0603 | C14663 | Basic | [Supplier listing](https://www.lcsc.com/product-detail/C14663.html); exact datasheet qualification pending | Default fitted; ratings/DFM review pending; indexed stock 12618106 checked 2026-10-06T21:20:03.578Z |
| C15 | MotorDriver: TMC_5VOUT, GND | SAMSUNG(三星) | CL21A475KBQNNNE | 0805 | C98192 | Extended | [Supplier listing](https://www.lcsc.com/product-detail/C98192.html); exact datasheet qualification pending | Default fitted; ratings/DFM review pending; indexed stock 205786 checked 2026-10-06T21:20:04.094Z |
| C16 | MotorDriver: GND, V3V3 | SAMSUNG(三星) | CL05B104KO5NNNC | 0402 | C1525 | Basic | [Supplier listing](https://www.lcsc.com/product-detail/C1525.html); exact datasheet qualification pending | Default fitted; ratings/DFM review pending; indexed stock 16407331 checked 2026-10-06T21:20:03.706Z |
| C17 | MotorDriver: VM, GND | YAGEO(国巨) | CC0603KRX7R9BB104 | 0603 | C14663 | Basic | [Supplier listing](https://www.lcsc.com/product-detail/C14663.html); exact datasheet qualification pending | Default fitted; ratings/DFM review pending; indexed stock 12618106 checked 2026-10-06T21:20:03.578Z |
| C18 | MotorDriver: VM, GND | SAMSUNG(三星) | CL31A106KBHNNNE | 1206 | C13585 | Basic | [Supplier listing](https://www.lcsc.com/product-detail/C13585.html); exact datasheet qualification pending | Default fitted; ratings/DFM review pending; indexed stock 1877266 checked 2026-10-06T21:20:03.802Z |
| C19 | MotorDriver: VM, GND | PANASONIC(松下) | EEEFPV101XAP | SMD,D6.3xL7.7mm | C178585 | Extended | [Manufacturer reference](https://industrial.panasonic.com/cdbs/www-data/pdf/RDE0000/ABA0000C1184.pdf) | Default fitted; ratings/DFM review pending; indexed stock 9716 checked 2026-10-06T21:20:04.009Z |
| C20 | MotorDriver: VM, GND | PANASONIC(松下) | EEEFPV101XAP | SMD,D6.3xL7.7mm | C178585 | Extended | [Manufacturer reference](https://industrial.panasonic.com/cdbs/www-data/pdf/RDE0000/ABA0000C1184.pdf) | Default fitted; ratings/DFM review pending; indexed stock 9716 checked 2026-10-06T21:20:04.009Z |
| C21 | MotorDriver: TMC_VREF, GND | SAMSUNG(三星) | CL05B104KO5NNNC | 0402 | C1525 | Basic | [Supplier listing](https://www.lcsc.com/product-detail/C1525.html); exact datasheet qualification pending | Default fitted; ratings/DFM review pending; indexed stock 16407331 checked 2026-10-06T21:20:03.706Z |
| C22 | UsbPd: GND, V3V3 | SAMSUNG(三星) | CL05B104KO5NNNC | 0402 | C1525 | Basic | [Supplier listing](https://www.lcsc.com/product-detail/C1525.html); exact datasheet qualification pending | Default fitted; ratings/DFM review pending; indexed stock 16407331 checked 2026-10-06T21:20:03.706Z |
| C23 | UsbPd: PD_CC1_CONN, GND | CCTC(三环) | TCC0402COG331J500AT | 0402 | C5448795 | Extended | [Supplier listing](https://www.lcsc.com/product-detail/C5448795.html); exact datasheet qualification pending | Default fitted; ratings/DFM review pending; indexed stock 2690 checked 2026-10-06T21:20:04.104Z |
| C24 | UsbPd: PD_CC2_CONN, GND | CCTC(三环) | TCC0402COG331J500AT | 0402 | C5448795 | Extended | [Supplier listing](https://www.lcsc.com/product-detail/C5448795.html); exact datasheet qualification pending | Default fitted; ratings/DFM review pending; indexed stock 2690 checked 2026-10-06T21:20:04.104Z |
| C25 | UsbPd: VBUS_CONN, GND | TAIYO YUDEN(太诱) | UMK107BBJ225KA-T | 0603 | C268016 | Extended | [Manufacturer reference](https://ds.yuden.co.jp/TYCOMPAS/ut/detail?pn=MSASU168BB5225KTNA01&u=M) | Default fitted; ratings/DFM review pending; indexed stock 37 checked 2026-10-06T21:20:04.109Z |
| C26 | UsbPd: VBUS_CONN, GND | YAGEO(国巨) | CC0603KRX7R9BB104 | 0603 | C14663 | Basic | [Supplier listing](https://www.lcsc.com/product-detail/C14663.html); exact datasheet qualification pending | Default fitted; ratings/DFM review pending; indexed stock 12618106 checked 2026-10-06T21:20:03.578Z |
| C27 | UsbPd: GND, VBUS_ADC | SAMSUNG(三星) | CL05B104KO5NNNC | 0402 | C1525 | Basic | [Supplier listing](https://www.lcsc.com/product-detail/C1525.html); exact datasheet qualification pending | Default fitted; ratings/DFM review pending; indexed stock 16407331 checked 2026-10-06T21:20:03.706Z |
| C28 | Programming: V3V3, GND | SAMSUNG(三星) | CL05B104KO5NNNC | 0402 | C1525 | Basic | [Supplier listing](https://www.lcsc.com/product-detail/C1525.html); exact datasheet qualification pending | Default fitted; ratings/DFM review pending; indexed stock 16407331 checked 2026-10-06T21:20:03.706Z |
| C29 | Programming: V3V3, GND | SAMSUNG(三星) | CL05B104KO5NNNC | 0402 | C1525 | Basic | [Supplier listing](https://www.lcsc.com/product-detail/C1525.html); exact datasheet qualification pending | Default fitted; ratings/DFM review pending; indexed stock 16407331 checked 2026-10-06T21:20:03.706Z |
| C30 | Interfaces: GND, LIMIT1 | SAMSUNG(三星) | CL05B104KO5NNNC | 0402 | C1525 | Basic | [Supplier listing](https://www.lcsc.com/product-detail/C1525.html); exact datasheet qualification pending | Default fitted; ratings/DFM review pending; indexed stock 16407331 checked 2026-10-06T21:20:03.706Z |
| C31 | Interfaces: LIMIT2, GND | SAMSUNG(三星) | CL05B104KO5NNNC | 0402 | C1525 | Basic | [Supplier listing](https://www.lcsc.com/product-detail/C1525.html); exact datasheet qualification pending | Default fitted; ratings/DFM review pending; indexed stock 16407331 checked 2026-10-06T21:20:03.706Z |
| C32 | Interfaces: GND, V3V3 | SAMSUNG(三星) | CL05B104KO5NNNC | 0402 | C1525 | Basic | [Supplier listing](https://www.lcsc.com/product-detail/C1525.html); exact datasheet qualification pending | Default fitted; ratings/DFM review pending; indexed stock 16407331 checked 2026-10-06T21:20:03.706Z |
| C33 | InputPower: EFUSE_RTN, EFUSE_DVDT | TAIYO YUDEN(太诱) | UMK107BBJ225KA-T | 0603 | C268016 | Extended | [Manufacturer reference](https://ds.yuden.co.jp/TYCOMPAS/ut/detail?pn=MSASU168BB5225KTNA01&u=M) | Default fitted; ratings/DFM review pending; indexed stock 37 checked 2026-10-06T21:20:04.109Z |
| C34 | InputPower: GND, VBUS_PROTECTED | TAIYO YUDEN(太诱) | UMK107BBJ225KA-T | 0603 | C268016 | Extended | [Manufacturer reference](https://ds.yuden.co.jp/TYCOMPAS/ut/detail?pn=MSASU168BB5225KTNA01&u=M) | Default fitted; ratings/DFM review pending; indexed stock 37 checked 2026-10-06T21:20:04.109Z |
| D_CAN | Interfaces: CAN_H, CAN_L, GND | SEMTECH | SM712.TCT | SOT-23 | C12067 | Extended | [Supplier listing](https://www.lcsc.com/product-detail/C12067.html); exact datasheet qualification pending | Default fitted; ratings/DFM review pending; indexed stock 16687 checked 2026-10-06T21:20:04.089Z |
| D_IO1 | Interfaces: EXT_STEP_CONN, EXT_DIR_CONN, EXT_ENABLE_N_CONN, LIMIT1_CONN, GND | TI(德州仪器) | TPD4E05U06DQAR | USON-10(1x2.5) | C138714 | Extended | [Supplier listing](https://www.lcsc.com/product-detail/C138714.html); exact datasheet qualification pending | Default fitted; ratings/DFM review pending; indexed stock 94387 checked 2026-10-06T21:20:04.015Z |
| D_IO2 | Interfaces: GND, LIMIT2_CONN | TI(德州仪器) | TPD4E05U06DQAR | USON-10(1x2.5) | C138714 | Extended | [Supplier listing](https://www.lcsc.com/product-detail/C138714.html); exact datasheet qualification pending | Default fitted; ratings/DFM review pending; indexed stock 94387 checked 2026-10-06T21:20:04.015Z |
| D_USB | UsbPd: GND, USB_DP, USB_DM | TI(德州仪器) | TPD2EUSB30DRTR | SOT(9x3) | C97502 | Extended | [Manufacturer reference](https://www.ti.com/lit/ds/symlink/tpd2eusb30a.pdf) | Default fitted; ratings/DFM review pending; indexed stock 17104 checked 2026-10-06T21:20:04.383Z |
| D_VBUS | UsbPd: VBUS_CONN, GND | ST(意法半导体) | ESDA25P35-1U1M | DFN1610-2 | C1974707 | Extended | [Manufacturer reference](https://www.st.com/resource/en/datasheet/esda25p35-1u1m.pdf) | Default fitted; ratings/DFM review pending; indexed stock 7192 checked 2026-10-06T21:20:04.288Z |
| J_IO | Interfaces: EXT_STEP_CONN, GND, CAN_H, CAN_L, EXT_DIR_CONN, EXT_ENABLE_N_CONN, LIMIT1_CONN, LIMIT2_CONN | JST | SM10B-SRSS-TB(LF)(SN) | SMD,P=1mm,卧贴 | C160409 | Extended | [Manufacturer reference](https://www.jst-mfg.com/product/pdf/eng/eSH.pdf) | Default fitted; ratings/DFM review pending; indexed stock 35149 checked 2026-10-06T21:20:04.282Z |
| J_MOTOR | Interfaces: MOTOR_A1, MOTOR_A2, MOTOR_B1, MOTOR_B2, GND | JST | SM04B-GHS-TB(LF)(SN) | SMD,P=1.25mm,卧贴 | C189895 | Extended | [Manufacturer reference](https://www.jst-mfg.com/product/pdf/eng/eGH.pdf) | Default fitted; ratings/DFM review pending; indexed stock 6 checked 2026-10-06T21:20:04.289Z |
| J_SWD | Programming: SWDIO_CONN, GND, SWCLK_CONN, NRST_CONN | JST (official standard programmer package) | SM05B-SRSS-TB(LF)(SN) | SMD,P=1mm,卧贴 | C136657 | Extended | [Manufacturer reference](https://www.jst-mfg.com/product/pdf/eng/eSH.pdf) | Default fitted; ratings/DFM review pending; indexed stock 21859 checked 2026-10-06T21:20:04.363Z |
| J_USB | UsbPd: VBUS_CONN, GND, PD_CC1_CONN, PD_CC2_CONN, USB_DP, USB_DM | GCT | USB4110-GF-A | SMD | C5143397 | Extended | [Manufacturer reference](https://gct.co/connector/usb4110) | Default fitted; ratings/DFM review pending; indexed stock 3202 checked 2026-10-06T21:20:04.363Z |
| L1 | LogicPower: BUCK_SW, V3V3 | BOURNS | SRN6028C-3R9M | SMD,6x6mm | C19947652 | Extended | [Manufacturer reference](https://bourns.com/docs/Product-Datasheets/SRN6028C.pdf) | Default fitted; ratings/DFM review pending; indexed stock 91 checked 2026-10-06T21:20:04.568Z |
| LED_FAULT | Interfaces: LED_FAULT_A, GND | XINGLIGHT(成兴光) | XL-1608SYGC-06 | 0603 | C965805 | Extended | [Supplier listing](https://www.lcsc.com/product-detail/C965805.html); exact datasheet qualification pending | Default fitted; ratings/DFM review pending; indexed stock 841307 checked 2026-10-06T21:20:04.545Z |
| LED_POWER | Interfaces: LED_POWER_A, GND | XINGLIGHT(成兴光) | XL-1608SYGC-06 | 0603 | C965805 | Extended | [Supplier listing](https://www.lcsc.com/product-detail/C965805.html); exact datasheet qualification pending | Default fitted; ratings/DFM review pending; indexed stock 841307 checked 2026-10-06T21:20:04.545Z |
| LED_STATUS | Interfaces: LED_STATUS_A, GND | XINGLIGHT(成兴光) | XL-1608SYGC-06 | 0603 | C965805 | Extended | [Supplier listing](https://www.lcsc.com/product-detail/C965805.html); exact datasheet qualification pending | Default fitted; ratings/DFM review pending; indexed stock 841307 checked 2026-10-06T21:20:04.545Z |
| Q_ILIM | InputPower: POWER_HIGH_CURRENT, EFUSE_RTN, EFUSE_ILIM_SWITCH | DIODES(美台) | DMG1012T-7 | SOT-523 | C20512 | Extended | [Manufacturer reference](https://www.diodes.com/datasheet/download/DMG1012T.pdf) | Default fitted; ratings/DFM review pending; indexed stock 103195 checked 2026-10-06T21:20:04.586Z |
| Q_PD | UsbPd: VBUS_CONN, VBUS_PROTECTED, PD_GATE | ST(意法半导体) | STL11N3LLH6 | VDFN-8-Power | C2965326 | Extended | [Supplier listing](https://www.lcsc.com/product-detail/C2965326.html); exact datasheet qualification pending | Default fitted; ratings/DFM review pending; indexed stock 48 checked 2026-10-06T21:20:04.526Z |
| R1 | MCU: V3V3, NRST | UNI-ROYAL(厚声) | 0402WGF1002TCE | 0402 | C25744 | Basic | [Supplier listing](https://www.lcsc.com/product-detail/C25744.html); exact datasheet qualification pending | Default fitted; ratings/DFM review pending; indexed stock 1256270 checked 2026-10-06T21:20:04.762Z |
| R2 | I2C: V3V3, I2C_SCL | UNI-ROYAL(厚声) | 0402WGF4701TCE | 0402 | C25900 | Basic | [Supplier listing](https://www.lcsc.com/product-detail/C25900.html); exact datasheet qualification pending | Default fitted; ratings/DFM review pending; indexed stock 3285378 checked 2026-10-06T21:20:04.623Z |
| R3 | I2C: V3V3, I2C_SDA | UNI-ROYAL(厚声) | 0402WGF4701TCE | 0402 | C25900 | Basic | [Supplier listing](https://www.lcsc.com/product-detail/C25900.html); exact datasheet qualification pending | Default fitted; ratings/DFM review pending; indexed stock 3285378 checked 2026-10-06T21:20:04.623Z |
| R4 | MotorDriver: TMC_UART_TX, TMC_UART_RX | UNI-ROYAL(厚声) | 0402WGF1001TCE | 0402 | C11702 | Basic | [Supplier listing](https://www.lcsc.com/product-detail/C11702.html); exact datasheet qualification pending | Default fitted; ratings/DFM review pending; indexed stock 2610919 checked 2026-10-06T21:20:04.989Z |
| R5 | MotorDriver: TMC_SENSE_A, GND | YAGEO(国巨) | RT1206BRD071RL | 1206 | C513714 | Extended | [Supplier listing](https://www.lcsc.com/product-detail/C513714.html); exact datasheet qualification pending | Default fitted; ratings/DFM review pending; indexed stock 19683 checked 2026-10-06T21:20:05.164Z |
| R6 | MotorDriver: TMC_SENSE_B, GND | YAGEO(国巨) | RT1206BRD071RL | 1206 | C513714 | Extended | [Supplier listing](https://www.lcsc.com/product-detail/C513714.html); exact datasheet qualification pending | Default fitted; ratings/DFM review pending; indexed stock 19683 checked 2026-10-06T21:20:05.164Z |
| R7 | MotorDriver: TMC_ENABLE_N, V3V3 | UNI-ROYAL(厚声) | 0402WGF1002TCE | 0402 | C25744 | Basic | [Supplier listing](https://www.lcsc.com/product-detail/C25744.html); exact datasheet qualification pending | Default fitted; ratings/DFM review pending; indexed stock 1256270 checked 2026-10-06T21:20:04.762Z |
| R8 | MotorDriver: TMC_STEP, GND | UNI-ROYAL(厚声) | 0402WGF1002TCE | 0402 | C25744 | Basic | [Supplier listing](https://www.lcsc.com/product-detail/C25744.html); exact datasheet qualification pending | Default fitted; ratings/DFM review pending; indexed stock 1256270 checked 2026-10-06T21:20:04.762Z |
| R9 | MotorDriver: TMC_DIR, GND | UNI-ROYAL(厚声) | 0402WGF1002TCE | 0402 | C25744 | Basic | [Supplier listing](https://www.lcsc.com/product-detail/C25744.html); exact datasheet qualification pending | Default fitted; ratings/DFM review pending; indexed stock 1256270 checked 2026-10-06T21:20:04.762Z |
| R10 | MotorDriver: TMC_5VOUT, TMC_VREF | UNI-ROYAL(厚声) | 0402WGF1002TCE | 0402 | C25744 | Basic | [Supplier listing](https://www.lcsc.com/product-detail/C25744.html); exact datasheet qualification pending | Default fitted; ratings/DFM review pending; indexed stock 1256270 checked 2026-10-06T21:20:04.762Z |
| R11 | MotorDriver: TMC_VREF, GND | UNI-ROYAL(厚声) | 0402WGF1002TCE | 0402 | C25744 | Basic | [Supplier listing](https://www.lcsc.com/product-detail/C25744.html); exact datasheet qualification pending | Default fitted; ratings/DFM review pending; indexed stock 1256270 checked 2026-10-06T21:20:04.762Z |
| R12 | UsbPd: V3V3, PD_FLT | UNI-ROYAL(厚声) | 0402WGF1002TCE | 0402 | C25744 | Basic | [Supplier listing](https://www.lcsc.com/product-detail/C25744.html); exact datasheet qualification pending | Default fitted; ratings/DFM review pending; indexed stock 1256270 checked 2026-10-06T21:20:04.762Z |
| R13 | UsbPd: VBUS_CONN, PD_OVP_SERIES | YAGEO(国巨) | RT0402BRD07100KL | 0402 | C852472 | Extended | [Supplier listing](https://www.lcsc.com/product-detail/C852472.html); exact datasheet qualification pending | Default fitted; ratings/DFM review pending; indexed stock 470011 checked 2026-10-06T21:20:04.988Z |
| R14 | UsbPd: PD_OVP_SERIES, PD_OVP | UNI-ROYAL(厚声) | 0402WGF1001TCE | 0402 | C11702 | Basic | [Supplier listing](https://www.lcsc.com/product-detail/C11702.html); exact datasheet qualification pending | Default fitted; ratings/DFM review pending; indexed stock 2610919 checked 2026-10-06T21:20:04.989Z |
| R15 | UsbPd: PD_OVP, GND | YAGEO(国巨) | RT0402BRD076K04L | 0402 | C852895 | Extended | [Supplier listing](https://www.lcsc.com/product-detail/C852895.html); exact datasheet qualification pending | Default fitted; ratings/DFM review pending; indexed stock 18162 checked 2026-10-06T21:20:04.970Z |
| R16 | UsbPd: VBUS_PROTECTED, VBUS_DIV | UNI-ROYAL(厚声) | 0402WGF2203TCE | 0402 | C25767 | Extended | [Supplier listing](https://www.lcsc.com/product-detail/C25767.html); exact datasheet qualification pending | Default fitted; ratings/DFM review pending; indexed stock 21067 checked 2026-10-06T21:20:04.970Z |
| R17 | UsbPd: GND, VBUS_DIV | UNI-ROYAL(厚声) | 0402WGF1002TCE | 0402 | C25744 | Basic | [Supplier listing](https://www.lcsc.com/product-detail/C25744.html); exact datasheet qualification pending | Default fitted; ratings/DFM review pending; indexed stock 1256270 checked 2026-10-06T21:20:04.762Z |
| R18 | UsbPd: VBUS_DIV, VBUS_ADC_PRE_GUARD | UNI-ROYAL(厚声) | 0402WGF1001TCE | 0402 | C11702 | Basic | [Supplier listing](https://www.lcsc.com/product-detail/C11702.html); exact datasheet qualification pending | Default fitted; ratings/DFM review pending; indexed stock 2610919 checked 2026-10-06T21:20:04.989Z |
| R19 | Programming: V3V3, POWER_GOOD | UNI-ROYAL(厚声) | 0402WGF1002TCE | 0402 | C25744 | Basic | [Supplier listing](https://www.lcsc.com/product-detail/C25744.html); exact datasheet qualification pending | Default fitted; ratings/DFM review pending; indexed stock 1256270 checked 2026-10-06T21:20:04.762Z |
| R20 | Programming: SWDIO_GUARDED, SWDIO | UNI-ROYAL(厚声) | 0402WGF1000TCE | 0402 | C25076 | Basic | [Supplier listing](https://www.lcsc.com/product-detail/C25076.html); exact datasheet qualification pending | Default fitted; ratings/DFM review pending; indexed stock 3055883 checked 2026-10-06T21:20:04.970Z |
| R21 | Programming: SWCLK, SWCLK_GUARDED | UNI-ROYAL(厚声) | 0402WGF1000TCE | 0402 | C25076 | Basic | [Supplier listing](https://www.lcsc.com/product-detail/C25076.html); exact datasheet qualification pending | Default fitted; ratings/DFM review pending; indexed stock 3055883 checked 2026-10-06T21:20:04.970Z |
| R22 | Programming: NRST_GUARDED, NRST | UNI-ROYAL(厚声) | 0402WGF1000TCE | 0402 | C25076 | Basic | [Supplier listing](https://www.lcsc.com/product-detail/C25076.html); exact datasheet qualification pending | Default fitted; ratings/DFM review pending; indexed stock 3055883 checked 2026-10-06T21:20:04.970Z |
| R23 | Interfaces: EXT_STEP_CONN, EXT_STEP | UNI-ROYAL(厚声) | 0402WGF1001TCE | 0402 | C11702 | Basic | [Supplier listing](https://www.lcsc.com/product-detail/C11702.html); exact datasheet qualification pending | Default fitted; ratings/DFM review pending; indexed stock 2610919 checked 2026-10-06T21:20:04.989Z |
| R24 | Interfaces: EXT_DIR, EXT_DIR_CONN | UNI-ROYAL(厚声) | 0402WGF1001TCE | 0402 | C11702 | Basic | [Supplier listing](https://www.lcsc.com/product-detail/C11702.html); exact datasheet qualification pending | Default fitted; ratings/DFM review pending; indexed stock 2610919 checked 2026-10-06T21:20:04.989Z |
| R25 | Interfaces: EXT_ENABLE_N_CONN, EXT_ENABLE_N | UNI-ROYAL(厚声) | 0402WGF1001TCE | 0402 | C11702 | Basic | [Supplier listing](https://www.lcsc.com/product-detail/C11702.html); exact datasheet qualification pending | Default fitted; ratings/DFM review pending; indexed stock 2610919 checked 2026-10-06T21:20:04.989Z |
| R26 | Interfaces: LIMIT1_CONN, LIMIT1 | UNI-ROYAL(厚声) | 0402WGF1001TCE | 0402 | C11702 | Basic | [Supplier listing](https://www.lcsc.com/product-detail/C11702.html); exact datasheet qualification pending | Default fitted; ratings/DFM review pending; indexed stock 2610919 checked 2026-10-06T21:20:04.989Z |
| R27 | Interfaces: LIMIT2_CONN, LIMIT2 | UNI-ROYAL(厚声) | 0402WGF1001TCE | 0402 | C11702 | Basic | [Supplier listing](https://www.lcsc.com/product-detail/C11702.html); exact datasheet qualification pending | Default fitted; ratings/DFM review pending; indexed stock 2610919 checked 2026-10-06T21:20:04.989Z |
| R28 | Interfaces: EXT_STEP, GND | UNI-ROYAL(厚声) | 0402WGF1002TCE | 0402 | C25744 | Basic | [Supplier listing](https://www.lcsc.com/product-detail/C25744.html); exact datasheet qualification pending | Default fitted; ratings/DFM review pending; indexed stock 1256270 checked 2026-10-06T21:20:04.762Z |
| R29 | Interfaces: EXT_DIR, GND | UNI-ROYAL(厚声) | 0402WGF1002TCE | 0402 | C25744 | Basic | [Supplier listing](https://www.lcsc.com/product-detail/C25744.html); exact datasheet qualification pending | Default fitted; ratings/DFM review pending; indexed stock 1256270 checked 2026-10-06T21:20:04.762Z |
| R30 | Interfaces: V3V3, EXT_ENABLE_N | UNI-ROYAL(厚声) | 0402WGF1002TCE | 0402 | C25744 | Basic | [Supplier listing](https://www.lcsc.com/product-detail/C25744.html); exact datasheet qualification pending | Default fitted; ratings/DFM review pending; indexed stock 1256270 checked 2026-10-06T21:20:04.762Z |
| R31 | Interfaces: V3V3, LIMIT1 | UNI-ROYAL(厚声) | 0402WGF1002TCE | 0402 | C25744 | Basic | [Supplier listing](https://www.lcsc.com/product-detail/C25744.html); exact datasheet qualification pending | Default fitted; ratings/DFM review pending; indexed stock 1256270 checked 2026-10-06T21:20:04.762Z |
| R32 | Interfaces: V3V3, LIMIT2 | UNI-ROYAL(厚声) | 0402WGF1002TCE | 0402 | C25744 | Basic | [Supplier listing](https://www.lcsc.com/product-detail/C25744.html); exact datasheet qualification pending | Default fitted; ratings/DFM review pending; indexed stock 1256270 checked 2026-10-06T21:20:04.762Z |
| R33 | Interfaces: V3V3, TEMP_ALERT_N | UNI-ROYAL(厚声) | 0402WGF1002TCE | 0402 | C25744 | Basic | [Supplier listing](https://www.lcsc.com/product-detail/C25744.html); exact datasheet qualification pending | Default fitted; ratings/DFM review pending; indexed stock 1256270 checked 2026-10-06T21:20:04.762Z |
| R34 | Interfaces: V3V3, CAN_RS | UNI-ROYAL(厚声) | 0402WGF1002TCE | 0402 | C25744 | Basic | [Supplier listing](https://www.lcsc.com/product-detail/C25744.html); exact datasheet qualification pending | Default fitted; ratings/DFM review pending; indexed stock 1256270 checked 2026-10-06T21:20:04.762Z |
| R35 | Interfaces: V3V3, LED_POWER_A | UNI-ROYAL(厚声) | 0402WGF1001TCE | 0402 | C11702 | Basic | [Supplier listing](https://www.lcsc.com/product-detail/C11702.html); exact datasheet qualification pending | Default fitted; ratings/DFM review pending; indexed stock 2610919 checked 2026-10-06T21:20:04.989Z |
| R36 | Interfaces: LED_STATUS_DRIVE, LED_STATUS_A | UNI-ROYAL(厚声) | 0402WGF1001TCE | 0402 | C11702 | Basic | [Supplier listing](https://www.lcsc.com/product-detail/C11702.html); exact datasheet qualification pending | Default fitted; ratings/DFM review pending; indexed stock 2610919 checked 2026-10-06T21:20:04.989Z |
| R37 | Interfaces: LED_FAULT_DRIVE, LED_FAULT_A | UNI-ROYAL(厚声) | 0402WGF1001TCE | 0402 | C11702 | Basic | [Supplier listing](https://www.lcsc.com/product-detail/C11702.html); exact datasheet qualification pending | Default fitted; ratings/DFM review pending; indexed stock 2610919 checked 2026-10-06T21:20:04.989Z |
| R38 | InputPower: VBUS_PROTECTED, EFUSE_EN | YAGEO(国巨) | RT0402BRD07100KL | 0402 | C852472 | Extended | [Supplier listing](https://www.lcsc.com/product-detail/C852472.html); exact datasheet qualification pending | Default fitted; ratings/DFM review pending; indexed stock 470011 checked 2026-10-06T21:20:04.988Z |
| R39 | InputPower: EFUSE_RTN, EFUSE_EN | UNI-ROYAL(厚声) | 0402WGF4702TCE | 0402 | C25792 | Basic | [Supplier listing](https://www.lcsc.com/product-detail/C25792.html); exact datasheet qualification pending | Default fitted; ratings/DFM review pending; indexed stock 1365510 checked 2026-10-06T21:20:05.370Z |
| R40 | InputPower: VBUS_PROTECTED, EFUSE_OVP_TOP_1 | YAGEO(国巨) | RT0402BRD07100KL | 0402 | C852472 | Extended | [Supplier listing](https://www.lcsc.com/product-detail/C852472.html); exact datasheet qualification pending | Default fitted; ratings/DFM review pending; indexed stock 470011 checked 2026-10-06T21:20:04.988Z |
| R41 | InputPower: EFUSE_OVP_TOP_1, EFUSE_OVP_TOP_2 | UNI-ROYAL(厚声) | 0402WGF1001TCE | 0402 | C11702 | Basic | [Supplier listing](https://www.lcsc.com/product-detail/C11702.html); exact datasheet qualification pending | Default fitted; ratings/DFM review pending; indexed stock 2610919 checked 2026-10-06T21:20:04.989Z |
| R42 | InputPower: EFUSE_OVP_TOP_2, EFUSE_OVP | UNI-ROYAL(厚声) | 0402WGF4701TCE | 0402 | C25900 | Basic | [Supplier listing](https://www.lcsc.com/product-detail/C25900.html); exact datasheet qualification pending | Default fitted; ratings/DFM review pending; indexed stock 3285378 checked 2026-10-06T21:20:04.623Z |
| R43 | InputPower: EFUSE_RTN, EFUSE_OVP | YAGEO(国巨) | RT0402BRD076K04L | 0402 | C852895 | Extended | [Supplier listing](https://www.lcsc.com/product-detail/C852895.html); exact datasheet qualification pending | Default fitted; ratings/DFM review pending; indexed stock 18162 checked 2026-10-06T21:20:04.970Z |
| R44 | InputPower: EFUSE_ILIM, EFUSE_RTN | UNI-ROYAL(厚声) | 0402WGF2402TCE | 0402 | C25769 | Extended | [Supplier listing](https://www.lcsc.com/product-detail/C25769.html); exact datasheet qualification pending | Default fitted; ratings/DFM review pending; indexed stock 18727 checked 2026-10-06T21:20:05.423Z |
| R45 | InputPower: EFUSE_ILIM, EFUSE_ILIM_SWITCH | UNI-ROYAL(厚声) | 0402WGF2402TCE | 0402 | C25769 | Extended | [Supplier listing](https://www.lcsc.com/product-detail/C25769.html); exact datasheet qualification pending | Default fitted; ratings/DFM review pending; indexed stock 18727 checked 2026-10-06T21:20:05.423Z |
| R46 | InputPower: GND, POWER_HIGH_CURRENT | UNI-ROYAL(厚声) | 0402WGF1002TCE | 0402 | C25744 | Basic | [Supplier listing](https://www.lcsc.com/product-detail/C25744.html); exact datasheet qualification pending | Default fitted; ratings/DFM review pending; indexed stock 1256270 checked 2026-10-06T21:20:04.762Z |
| R48 | InputPower: EFUSE_FLT_N, V3V3 | UNI-ROYAL(厚声) | 0402WGF1002TCE | 0402 | C25744 | Basic | [Supplier listing](https://www.lcsc.com/product-detail/C25744.html); exact datasheet qualification pending | Default fitted; ratings/DFM review pending; indexed stock 1256270 checked 2026-10-06T21:20:04.762Z |
| R49 | CAN: CAN_H, CAN_TERM_LINK | UNI-ROYAL(厚声) | 0402WGF1200TCE | 0402 | C25079 | Basic | [Supplier listing](https://www.lcsc.com/product-detail/C25079.html); exact datasheet qualification pending | Default fitted; ratings/DFM review pending; indexed stock 387706 checked 2026-10-06T21:20:05.388Z |
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

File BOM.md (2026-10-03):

# Current BOM revision 16

111 references /108 default fitted /43 active exact JLCPCB identities. Current authoritative candidate table: BOM-CURRENT.md and evidence/rev-0.0.16-alpha.0/REVIEW-BOM.json. U4/C6/R50 DNP; all electronics retain official definitions. Indexed catalogue checks passed 2026-10-03; not reserved assembler inventory. U10=C2155767, R44/R45=C25769, Q_ILIM=C20512, C33/C34/C25=C268016. Fabrication BOM/CPL remain pending actual routed revision. Historical selections below are superseded where different.

# Current review BOM — 0.0.15-alpha.0

**Design review only; not an approved fabrication BOM.** All 111 instantiated components have exact JLCPCB identities. The generated [per-reference review BOM](evidence/rev-0.0.15-alpha.0/REVIEW-BOM.csv) and [JSON record](evidence/rev-0.0.15-alpha.0/REVIEW-BOM.json) come from the current schematic.

The default open-loop review assembly fits 108 parts and omits U4/C6 (optional encoder) and R50 (CAN termination link). Retain R2/R3: the temperature sensor still requires I²C pull-ups. Manufacturing exports must apply the same population manifest to both BOM and placement files; that fabrication export has not been performed.

See [the complete 111-reference candidate table](BOM-CURRENT.md) for values, manufacturer identities, circuit roles and current catalogue evidence. Indexed stock is not an assembler reservation.

Changes superseding every historical proposal below:

- R5/R6: **C513714**, Yageo RT1206BRD071RL, 1 Ω, ±0.1%, 25 ppm/°C, 0.25 W. The 180 mΩ sense pair is no longer active. R10/R11 are both 10 kΩ.
- J_USB: **C5143397**, GCT USB4110-GF-A. B4 manufacturer footprint audit passes; the external exact-part TraceParts STEP passes nominal registration and rendered-contact checks. Full mounted fit remains unqualified.
- J_MOTOR: **C189895**, JST SM04B-GHS-TB(LF)(SN), GH 1.25 mm, 1 A with AWG26. Mates with GHR-04V-S and SSHL-002T-P0.2 contacts. Search showed only six supplier units on 2026-10-03; stock must be rechecked before ordering. C265102/C265332/C157926 are excluded following footprint review.
- J_IO: **C160409**, JST SM10B-SRSS-TB(LF)(SN), SH ten-position side entry. Full footprint/model and mating harness qualification remains pending.
- J_SWD: **C136657**, official package 0.8.0. Pin 1 VOUT is intentionally disconnected; signal voltage must be 3.3 V. USB powers the board.
- U7: **C2673275**, TMUX1511RSVR, isolates programmer signals and the VBUS ADC while unpowered.
- U8: **C5218924**, TLV803EA30DBZR, 3.0 V supervisor with 200 ms reset delay; GND1/RESET2/VDD3. C53283913 is excluded because its released import loses the rotated centre-pad geometry.
- U9: **C28927**, TMP112AIDRLR, board temperature at I²C address 0x48.
- U10: **C2155767**, TPS26600RHFR, protected VM feeding both buck and motor. Controlled charging and reverse blocking do not provide a regenerative brake.
- D_IO1/D_IO2: **C138714**; D_CAN: **C12067**; Q_ILIM: **C20512**, DMG1012T-7; three LEDs: **C965805**.

Current imports and physical-pin connectivity pass their limited audit scopes. Availability of the complete assembly, effective capacitance, startup budget, transient protection, thermal ratings and all mechanical interfaces remain unqualified. No generic or manually patched component definitions are used.

- R44/R45: **C25769**, 24 kΩ ±1%, official native resistor import. R42 is 4.7 kΩ C25900; MODE connects to isolated EFUSE_RTN for current limiting with automatic retry.
- C33/C34: **C268016**, 2.2 µF/50 V X5R. C33 controls dV/dt and C34 bypasses the protected input. C25 uses the same part. R47 is removed.
- C852665 and C181406 are rejected alternatives, excluded from the active board because their imports failed value/footprint review. No definition was repaired manually.

## Historical BOM proposals — superseded by the current per-reference record

# Current revision 0.0.9-alpha.0 update

Selected motor: STEPPERONLINE 14HM11-0404S; 0.4 A/phase, 25 ohms,
24 mH, 0.9° (400 full steps/revolution), single front shaft. Previous motor
ratings/current-limit proposals and rear encoder mechanics below are retired.
No firmware current limit is implemented or tested. Optional AS5600 electrical
draft remains while feedback selection is pending. Motor attachment is blocked
pending rear fastener specification or a qualified carrier. Electronic supplier
imports and partial connectivity are unchanged; USB footprint/protection blockers
remain. See [current validation](VALIDATION.md).

## Previous electrical draft and historical motor proposals

# Candidate BOM - NOT READY

Revision 0.0.7-alpha.0; identity/import checks 2026-10-03 local time.
Six draft sheets instantiate U1-U6, C1-C27, R1-R18, L1, J_USB, Q_PD, D_USB and D_VBUS (56 parts).
Other rows are candidates or unfinished coverage items, not an assembly BOM.
Basic/Extended below is the class reported by the fetched supplier JSON;
reported LCSC stock is not a reservation or verified current JLC assembly stock.
Ratings, footprint/model registration, assembler inventory and substitutions
remain subject to stage 2 qualification.

| Ref | Function | Manufacturer | MPN | Package | LCSC/JLCPCB Part Number | Basic/Extended | Datasheet | Notes |
| --- | --- | --- | --- | --- | --- | --- | --- | --- |
| U1 | MCU, USB, UCPD, FDCAN | ST | STM32G0B1CBT6 | LQFP48, 7 x 7 mm | C2847904 | Extended | [ST DS13560](https://www.st.com/resource/en/datasheet/stm32g0b1cb.pdf) | Regenerated with official CLI 0.1.2232 / easyeda 0.0.368; critical-label audit PASS; MCU draft instantiated |
| U2 | Stepper driver | ADI/Trinamic | TMC2209-LA | QFN28 exposed pad, 5 x 5 mm | C465949 | Extended | [ADI Rev 1.09](https://www.analog.com/media/en/technical-documentation/data-sheets/TMC2209_datasheet_rev1.09.pdf) | Latest official import regenerated; draft instantiated with support/sense network; 5 V fallback motor disabled; full footprint/paste/thermal review pending |
| U3 | USB PD protection | ST | TCPP01-M12 | QFN12 exposed pad, 3 x 3 mm | C1121848 | Extended | [ST DS12900](https://www.st.com/resource/en/datasheet/tcpp01-m12.pdf) | Regenerated with official CLI 0.1.2232 / easyeda 0.0.368; DB/FLT audit PASS; frontend instantiated; downstream protection qualification BLOCKED; protection does not negotiate PD |
| U4 | Optional magnetic encoder | ams | AS5600-ASOM | SOIC8 | C79815 | Extended | [Manufacturer-authored datasheet](https://datasheet.lcsc.com/datasheet/pdf/fab02cf30a2c48b5aeeebf03db9fe675.pdf?productCode=C79815) | Latest official import regenerated; 3.3 V I2C draft instantiated; optional U4/C6 population; bottom mechanics and models pending |
| U5 | 3.3 V logic buck | Diodes | AP63203WU-7 | TSOT26 | C780769 | Extended | [Diodes DS41326 Rev 3-2](https://www.diodes.com/datasheet/download/AP63200-AP63201-AP63203-AP63205.pdf) | Imported unchanged; draft instantiated; input power path, effective capacitance and thermal qualification pending |
| U6 | Classical CAN candidate | TI | SN65HVD230DR | SOIC8 | C12084 | Extended | [TI datasheet](https://www.ti.com/lit/ds/symlink/sn65hvd230.pdf) | Imported with easyeda 0.0.360; draft instantiated, RS=GND; termination/ESD pending; no CAN FD claim |
| C1 | MCU VDD 100 nF | Samsung | CL05B104KO5NNNC | 0402 | C1525 | Basic | [Supplier datasheet](https://www.lcsc.com/datasheet/C1525.pdf) | X7R, 16 V; imported unchanged; placement pending |
| C3 | MCU VREF+ 100 nF | Samsung | CL05B104KO5NNNC | 0402 | C1525 | Basic | [Supplier datasheet](https://www.lcsc.com/datasheet/C1525.pdf) | X7R, 16 V; imported unchanged; placement pending |
| C4 | MCU VBAT 100 nF | Samsung | CL05B104KO5NNNC | 0402 | C1525 | Basic | [Supplier datasheet](https://www.lcsc.com/datasheet/C1525.pdf) | X7R, 16 V; imported unchanged; placement pending |
| C5 | Reset filter 100 nF | Samsung | CL05B104KO5NNNC | 0402 | C1525 | Basic | [Supplier datasheet](https://www.lcsc.com/datasheet/C1525.pdf) | X7R, 16 V; imported unchanged; placement pending |
| C6 | Encoder supply 100 nF | Samsung | CL05B104KO5NNNC | 0402 | C1525 | Basic | [Supplier datasheet](https://www.lcsc.com/datasheet/C1525.pdf) | X7R, 16 V; imported unchanged; placement pending |
| C7 | CAN supply 100 nF | Samsung | CL05B104KO5NNNC | 0402 | C1525 | Basic | [Supplier datasheet](https://www.lcsc.com/datasheet/C1525.pdf) | X7R, 16 V; imported unchanged; placement pending |
| C2 | MCU bulk 4.7 uF nominal | Samsung | CL05A475MP5NRNC | 0402 | C23733 | Basic | [Supplier datasheet](https://www.lcsc.com/datasheet/C23733.pdf) | X5R, 10 V; effective 3.3 V capacitance not qualified |
| R1 | Reset pull-up 10 kOhm | UniRoyal | 0402WGF1002TCE | 0402 | C25744 | Basic | [Supplier datasheet](https://www.lcsc.com/datasheet/C25744.pdf) | 1%; imported unchanged |
| R2 | I2C SCL pull-up 4.7 kOhm | UniRoyal | 0402WGF4701TCE | 0402 | C25900 | Basic | [Supplier datasheet](https://www.lcsc.com/datasheet/C25900.pdf) | 1%; bus capacitance/rise-time qualification pending |
| R3 | I2C SDA pull-up 4.7 kOhm | UniRoyal | 0402WGF4701TCE | 0402 | C25900 | Basic | [Supplier datasheet](https://www.lcsc.com/datasheet/C25900.pdf) | 1%; bus capacitance/rise-time qualification pending |
| C8 | Buck input 10 uF/50 V | Samsung | CL31A106KBHNNNE | 1206 | C13585 | Basic | [Supplier datasheet](https://www.lcsc.com/datasheet/C13585.pdf) | Effective input capacitance/ripple and controlled charging pending |
| C9 | Buck input HF 100 nF/50 V | Yageo | CC0603KRX7R9BB104 | 0603 | C14663 | Basic | [Supplier datasheet](https://www.lcsc.com/datasheet/C14663.pdf) | Close VIN/GND loop required |
| C10 | Buck bootstrap 100 nF/50 V | Yageo | CC0603KRX7R9BB104 | 0603 | C14663 | Basic | [Supplier datasheet](https://www.lcsc.com/datasheet/C14663.pdf) | BST to SW, not to ground |
| C11 | Buck output 22 uF/25 V | Samsung | CL21A226MAQNNNE | 0805 | C45783 | Basic | [Supplier datasheet](https://www.lcsc.com/datasheet/C45783.pdf) | Effective capacitance/loop stability pending |
| C12 | Buck output 22 uF/25 V | Samsung | CL21A226MAQNNNE | 0805 | C45783 | Basic | [Supplier datasheet](https://www.lcsc.com/datasheet/C45783.pdf) | Parallel C11; effective capacitance pending |
| C13 | TMC flying charge pump 22 nF/50 V | Samsung | CL05B223KB5VPNC | 0402 | C307335 | Extended | [Supplier datasheet](https://www.lcsc.com/datasheet/C307335.pdf) | Between CPO and CPI |
| C14 | TMC pump reservoir 100 nF/50 V | Yageo | CC0603KRX7R9BB104 | 0603 | C14663 | Basic | [Supplier datasheet](https://www.lcsc.com/datasheet/C14663.pdf) | VCP to VM, not ground |
| C15 | TMC 5VOUT regulator 4.7 uF/50 V | Samsung | CL21A475KBQNNNE | 0805 | C98192 | Extended | [Supplier datasheet](https://www.lcsc.com/datasheet/C98192.pdf) | Effective capacitance at 5 V must remain adequate |
| C16 | TMC VIO 100 nF/16 V | Samsung | CL05B104KO5NNNC | 0402 | C1525 | Basic | [Supplier datasheet](https://www.lcsc.com/datasheet/C1525.pdf) | 3.3 V logic |
| C17 | TMC VM HF 100 nF/50 V | Yageo | CC0603KRX7R9BB104 | 0603 | C14663 | Basic | [Supplier datasheet](https://www.lcsc.com/datasheet/C14663.pdf) | Near VS pins and EP |
| C18 | TMC VM ceramic 10 uF/50 V | Samsung | CL31A106KBHNNNE | 1206 | C13585 | Basic | [Supplier datasheet](https://www.lcsc.com/datasheet/C13585.pdf) | Effective capacitance at motor voltage pending |
| C19 | TMC VM bulk 100 uF/35 V | Panasonic | EEEFPV101XAP | SMD 6.3 x 7.7 mm | C178585 | Extended | [Supplier datasheet](https://www.lcsc.com/datasheet/C178585.pdf) | Polarized, pin1 positive; 600 mA/160 mOhm at 100 kHz; ripple/layout pending |
| C20 | TMC VM bulk 100 uF/35 V | Panasonic | EEEFPV101XAP | SMD 6.3 x 7.7 mm | C178585 | Extended | [Supplier datasheet](https://www.lcsc.com/datasheet/C178585.pdf) | Parallel C19; nominal 200 uF total, -20% minimum 160 uF; not a brake |
| C21 | TMC VREF filter 100 nF/16 V | Samsung | CL05B104KO5NNNC | 0402 | C1525 | Basic | [Supplier datasheet](https://www.lcsc.com/datasheet/C1525.pdf) | VREF to GND |
| R4 | TMC UART TX isolation 1 kOhm | UniRoyal | 0402WGF1001TCE | 0402 | C11702 | Basic | [Supplier datasheet](https://www.lcsc.com/datasheet/C11702.pdf) | TX through resistor, MCU RX directly on single-wire UART |
| R5 | TMC phase A sense 180 mOhm/1 W | Milliohm | HoLRT1206-1W-180mR-1% | 1206 | C5127775 | Extended | [Supplier record](https://www.lcsc.com/product-detail/C5127775.html) | 1%; fixed official native import, 0.18 Ω and both pads audited; nominal 1.149 A RMS full scale; proposed firmware cap 1 A; pulse/temperature/Kelvin review pending |
| R6 | TMC phase B sense 180 mOhm/1 W | Milliohm | HoLRT1206-1W-180mR-1% | 1206 | C5127775 | Extended | [Supplier record](https://www.lcsc.com/product-detail/C5127775.html) | Match R5; official footprint, no manual edits |
| R7 | TMC ENN pull-up 10 kOhm | UniRoyal | 0402WGF1002TCE | 0402 | C25744 | Basic | [Supplier datasheet](https://www.lcsc.com/datasheet/C25744.pdf) | Hardware disabled while MCU resets |
| R8 | TMC STEP pull-down 10 kOhm | UniRoyal | 0402WGF1002TCE | 0402 | C25744 | Basic | [Supplier datasheet](https://www.lcsc.com/datasheet/C25744.pdf) | Defined reset state |
| R9 | TMC DIR pull-down 10 kOhm | UniRoyal | 0402WGF1002TCE | 0402 | C25744 | Basic | [Supplier datasheet](https://www.lcsc.com/datasheet/C25744.pdf) | Defined reset state |
| R10 | TMC VREF upper 10 kOhm | UniRoyal | 0402WGF1002TCE | 0402 | C25744 | Basic | [Supplier datasheet](https://www.lcsc.com/datasheet/C25744.pdf) | From 5VOUT; review divider/regulator tolerances |
| R11 | TMC VREF lower 10 kOhm | UniRoyal | 0402WGF1002TCE | 0402 | C25744 | Basic | [Supplier datasheet](https://www.lcsc.com/datasheet/C25744.pdf) | To GND; nominal VREF 2.5 V |
| L1 | Buck 3.9 uH power inductor | Bourns | SRN6028C-3R9M | 6 x 6 mm, max 2.8 mm height | C19947652 | Extended | [Bourns datasheet](https://bourns.com/docs/Product-Datasheets/SRN6028C.pdf) | +/-20%; DCR 28 mOhm +/-20%; 3.3 A Irms / 3.9 A Isat typical at 25 C; own 6.5 mm lands reviewed; screening calculation updated |
| J_SWD | Official Standard JST SWD + Reset Side | JST | SM05B-SRSS-TB(LF)(SN) | JST SH 5-pin, 1 mm, side entry | C136657 | Unverified | [JST SH series](https://www.jst-mfg.com/product/pdf/eng/eSH.pdf) | Official package 0.8.0 installed; VOUT/VTREF distinction unresolved |
| J_USB | USB-C PD + USB2 receptacle | HRO | TYPE-C-31-M-12 | 16 native ports, SMT + shell slots | C165948 | Extended | [Manufacturer drawing](references/TYPE-C-31-M-12.pdf) | Draft instantiated; 5 A / 20 V nominal; footprint dimensions differ from drawing: BLOCKING Stage 2/3 issue |
| Q_PD | TCPP high-side sink MOSFET | ST | STL11N3LLH6 | PowerFLAT 3.3 x 3.3, supplier drain EP pin9 | C2965326 | Extended | [ST DocID17755](references/STL11N3LLH6.pdf) | 30 V; native draft instantiated; source/drain/EP links audited; not complete inrush/reverse/regen protection |
| Power-path parts | Inrush/current/reverse protection | BLOCKED selection | BLOCKED | BLOCKED | BLOCKED | Unverified | Pending | Qualification must precede connecting input to buck/motor |
| D_USB | USB data ESD | TI | TPD2EUSB30ADRTR | SOT-9X3-3 | C94934 | Extended | [TI Rev G](references/TPD2EUSB30A.pdf) | D+1/D-2/GND3; imported custom-symbol reference text missing, draft board annotation added |
| D_VBUS | Input TVS | ST | ESDA25P35-1U1M | DFN1610-2 | C1974707 | Extended | [Supplier datasheet](https://www.lcsc.com/datasheet/C1974707.pdf) | 22 V stand-off; not a 24 V clamp or motor brake; imported rotation issue blocks schematic visual qualification |
| C22 | TCPP decoupling 100 nF/16 V | Samsung | CL05B104KO5NNNC | 0402 | C1525 | Basic | [Supplier datasheet](https://www.lcsc.com/datasheet/C1525.pdf) | V3V3 to ground |
| C23 | CC1 330 pF/50 V | CCTC | TCC0402COG331J500AT | 0402 | C5448795 | Extended | [Supplier datasheet](https://www.lcsc.com/datasheet/C5448795.pdf) | C0G, +/-5%; official replacement for excluded X7R candidate; total capacitance qualification pending |
| C24 | CC2 330 pF/50 V | CCTC | TCC0402COG331J500AT | 0402 | C5448795 | Extended | [Supplier datasheet](https://www.lcsc.com/datasheet/C5448795.pdf) | Match C23; own unchanged official footprint |
| C25 | Input 2.2 uF/50 V | Taiyo Yuden | UMK107BBJ225KA-T | 0603 | C268016 | Extended | [Supplier datasheet](https://www.lcsc.com/datasheet/C268016.pdf) | X5R; effective capacitance/inrush pending |
| C26 | TCPP IN_GD HF 100 nF/50 V | Yageo | CC0603KRX7R9BB104 | 0603 | C14663 | Basic | [Supplier datasheet](https://www.lcsc.com/datasheet/C14663.pdf) | X7R; placement pending |
| C27 | VBUS ADC filter 100 nF/16 V | Samsung | CL05B104KO5NNNC | 0402 | C1525 | Basic | [Supplier datasheet](https://www.lcsc.com/datasheet/C1525.pdf) | Unpowered MCU injection unresolved |
| R12 | FLT pull-up 10 kOhm | UniRoyal | 0402WGF1002TCE | 0402 | C25744 | Basic | [Supplier datasheet](https://www.lcsc.com/datasheet/C25744.pdf) | Open-drain fault input |
| R13 | OVP upper 100 kOhm | Yageo | RT0402BRD07100KL | 0402 | C852472 | Extended | [Supplier datasheet](https://www.lcsc.com/datasheet/C852472.pdf) | 0.1%, 25 ppm/C; static screen only |
| R14 | OVP series 1 kOhm | UniRoyal | 0402WGF1001TCE | 0402 | C11702 | Basic | [Supplier datasheet](https://www.lcsc.com/datasheet/C11702.pdf) | 1%; exact TCR/leakage/loading qualification pending |
| R15 | OVP lower 6.04 kOhm | Yageo | RT0402BRD076K04L | 0402 | C852895 | Extended | [Supplier datasheet](https://www.lcsc.com/datasheet/C852895.pdf) | 0.1%, 25 ppm/C; transient margin BLOCKED |
| R16 | VBUS sense upper 220 kOhm | UniRoyal | 0402WGF2203TCE | 0402 | C25767 | Basic | [Supplier datasheet](https://www.lcsc.com/datasheet/C25767.pdf) | 1%; connected to protected output |
| R17 | VBUS sense lower 10 kOhm | UniRoyal | 0402WGF1002TCE | 0402 | C25744 | Basic | [Supplier datasheet](https://www.lcsc.com/datasheet/C25744.pdf) | 1%; measurement calibration required |
| R18 | VBUS ADC series 1 kOhm | UniRoyal | 0402WGF1001TCE | 0402 | C11702 | Basic | [Supplier datasheet](https://www.lcsc.com/datasheet/C11702.pdf) | 1%; part of ADC settling/filter network |
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

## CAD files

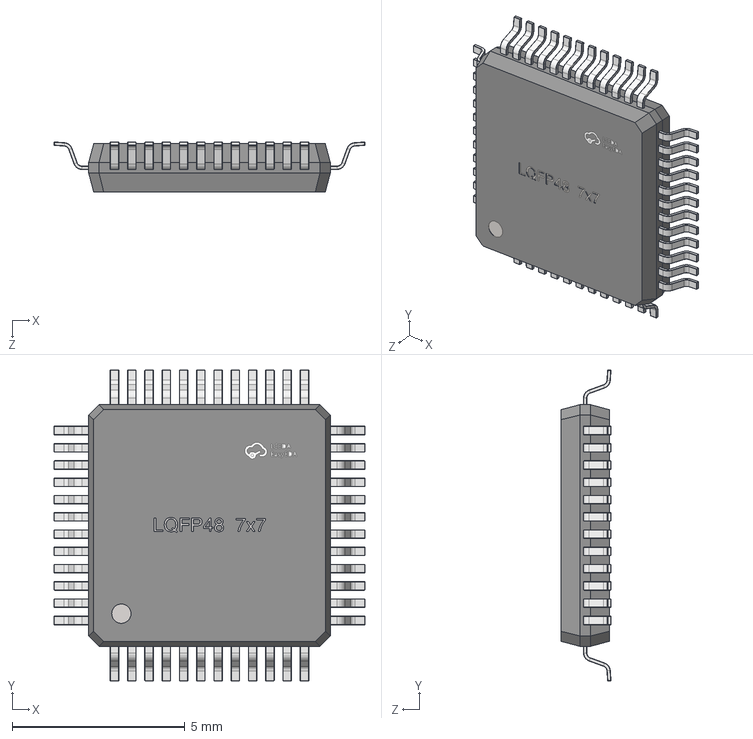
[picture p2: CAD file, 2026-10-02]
evidence/imports-tsci-0.0.2696/imports/STM32G0B1CBT6/STM32G0B1CBT6.step
9.01 x 9.01 x 1.45 mm

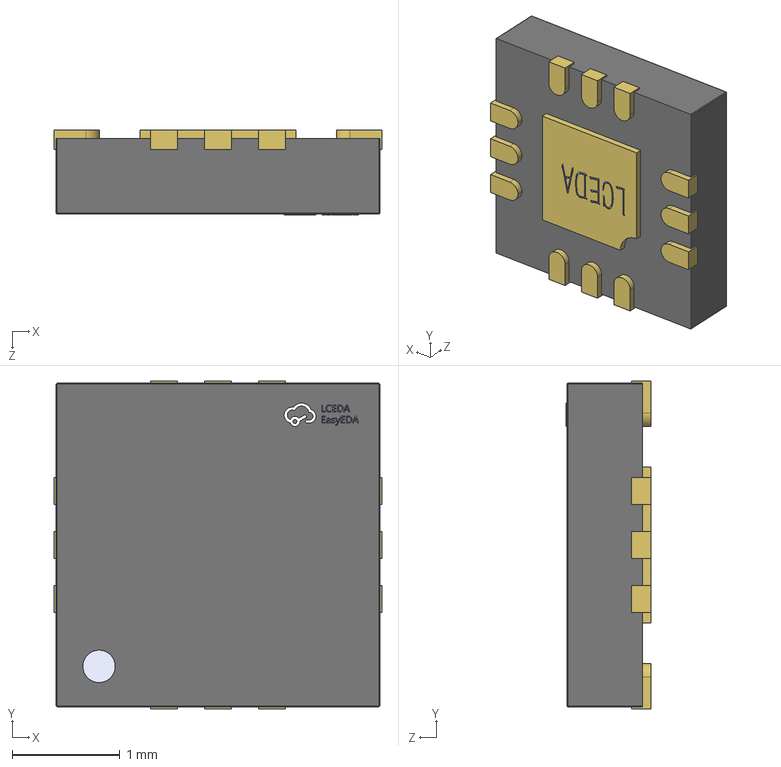
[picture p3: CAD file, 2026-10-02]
evidence/imports-tsci-0.0.2696/imports/TCPP01_M12/TCPP01_M12.step
3.04 x 3.04 x 0.79 mm

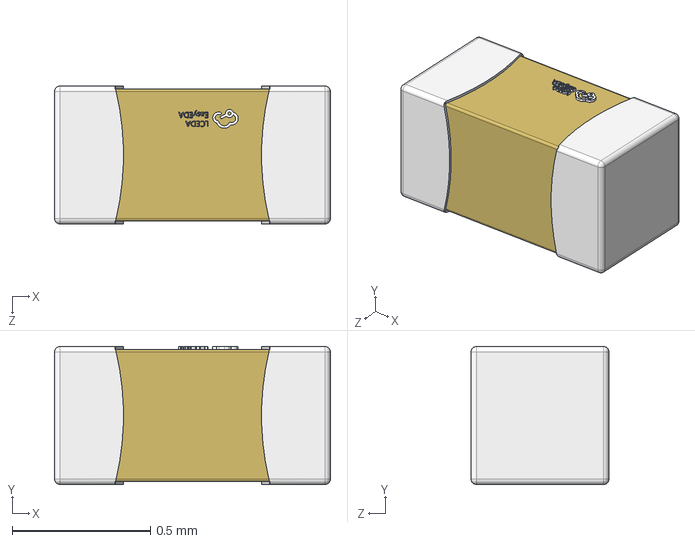
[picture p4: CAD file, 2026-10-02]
imports/A_0402CG300J500NT/A_0402CG300J500NT.step
1.00 x 0.5 x 0.5 mm

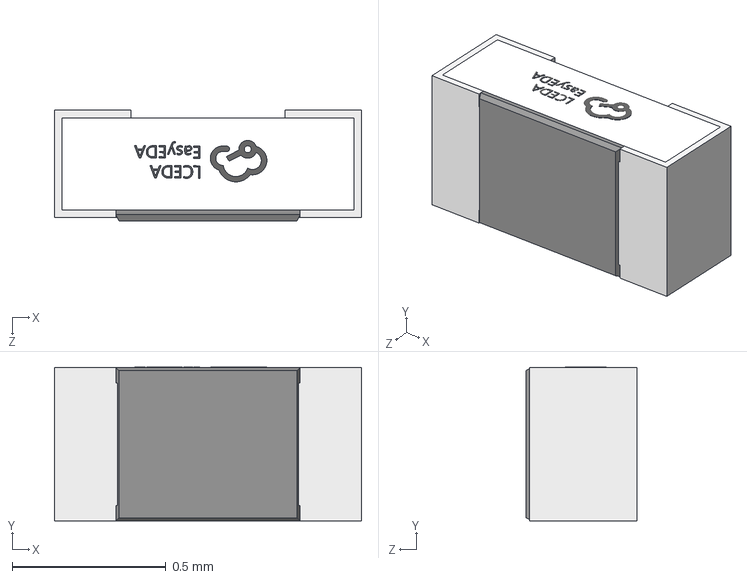
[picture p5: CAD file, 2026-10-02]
imports/A_0402WGF0000TCE/A_0402WGF0000TCE.step
1.00 x 0.501 x 0.36 mm

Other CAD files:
evidence/imports-tsci-0.0.2696/imports/STM32G0B1CBT6/STM32G0B1CBT6.obj
evidence/imports-tsci-0.0.2696/imports/TCPP01_M12/TCPP01_M12.obj
evidence/rev-0.0.2-alpha.0/pre-update-imports/STM32G0B1CBT6/STM32G0B1CBT6.obj
evidence/rev-0.0.2-alpha.0/pre-update-imports/TCPP01_M12/TCPP01_M12.obj
evidence/rev-0.0.7-alpha.0/previous-imports/STM32G0B1CBT6/STM32G0B1CBT6.obj
evidence/rev-0.0.7-alpha.0/previous-imports/TCPP01_M12/TCPP01_M12.obj
imports/ABM8_16_000MHZ_B2_T/ABM8_16_000MHZ_B2_T.obj
imports/ABM8_16_000MHZ_B2_T/ABM8_16_000MHZ_B2_T.step
imports/ABM8_272_T3/ABM8_272_T3.obj
imports/ABM8_272_T3/ABM8_272_T3.step
imports/AP63203WU_7/AP63203WU_7.obj
imports/AP63203WU_7/AP63203WU_7.step
imports/A_0402CG300J500NT/A_0402CG300J500NT.obj
imports/A_0402WGF1803TCE/A_0402WGF1803TCE.obj
imports/A_0402WGF5101TCE/A_0402WGF5101TCE.obj
imports/BAT54WS_7_F/BAT54WS_7_F.obj
imports/BAT54WS_7_F/BAT54WS_7_F.step
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

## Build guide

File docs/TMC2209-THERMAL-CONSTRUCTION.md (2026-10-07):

# TMC2209 exposed-pad thermal construction

ADI TMC2209 Rev1.09 §21.1–21.2 requires thermal conduction from the exposed
die pad into a solid ground plane. The original 62 ordinary vias had no via
within 3 mm of U2. The two outside-pad trial vias passed clearances, but actual
top copper erosion showed only a 0.15–0.20 mm connection neck. That trial is
preserved as unqualified thermal spreading; it is not the accepted solution.

The replacement uses five explicitly named native thermal vias within the
unchanged official U2 pin29 exposed pad. See
[`tmc2209-thermal-vias.json`](../src/routing/tmc2209-thermal-vias.json).
Each is a full four-layer through via with 0.30 mm drill and 0.45 mm pad.
The unchanged independent checker verifies that each annulus lies completely
inside its own ground pad and that every other pad, track, drill and keepout
retains its original clearance. Native filled-copper checks retain one physical
GND network. No supplier footprint, pin or model definition was edited.

These five features require **IPC-4761 Type VII epoxy filling and copper capping**,
with planar, solderable ENIG top caps. Bottom mask is tented; the top exposed
pad stays open. The official native board manufacturing flag allows this
intentional construction; autorouting still has `allowViaInPad=false`.
`scripts/check-tmc-thermal-vias.mjs` independently re-enables the original
official via-in-pad check for every emitted via and requires exactly these
five owner contacts, with zero unlisted or foreign contacts. The original
strict drill checker is unchanged. Reproducible negative fixtures reject a
wrong net, wrong drill, and an extra ordinary same-net pad contact.

Native solder paste remains the original 2.449995 × 2.449995 mm aperture over
the 3.499993 × 3.499993 mm exposed pad: 49% area coverage. Filled planar caps
are required to prevent solder wicking into the five holes. Confirm the exact
fill/cap coordinates, cap finish/flatness, top/bottom mask and exposed-pad
stencil treatment in the final JLCPCB CAM and assembly quote. Ordinary drill
files alone do not order selective filling/capping. Its added fabrication
cost is not yet quoted; do not silently substitute open via-in-pad holes.

The datasheet's 30 K/W value is for a 70 × 133 mm JEDEC board and does not
qualify this 35 × 35 mm controller. Actual barrel plating, copper stackup,
spreading resistance, linear-regulator and switching losses, ambient and
assembled motor/carrier conditions need the final loaded thermal review.
Physical temperature and load tests remain pending; thermal geometry passing
does not establish hardware operation or fabrication readiness.

Current thermal replay evidence:
[`thermal051`](../evidence/rev-0.0.50-alpha.0/routing/thermal051):
53/120 complete nets, 298 opens, 81 tracks and 67 vias, including these five
thermal features. There are zero other native errors and zero strict copper
violations. All previous 53 complete nets remain physically joined. This
thermal candidate has not changed the published routing count by itself.

The five thermal features are adopted in revision51 after the power059 replay:
54/120 complete nets,291 opens,87 tracks and71 total full through vias,zero other
native or unchanged strict errors. The direct thermal path and every prior
physical network remain intact after the FET-source repairs. CAM,quote and
loaded/hardware qualification remain pending.

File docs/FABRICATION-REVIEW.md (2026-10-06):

# Remaining fabrication review — 0.0.41-alpha.0

Latest continuation: a fresh exact official shop check confirms enough displayed
stock for one default board for **41/42 fitted codes** (107 of 108 fitted refs).
**U1 C2847904 remains the only missing fitted code.** Genuine ST Q_PD C2965326
has 100 units. All43 catalogue codes were queried, including the DNP part.
Shop stock does not establish assembler allocation. Additional genuine-ST
LQFP variants return no stocked drop-in; stocked QFN alternatives have a
different footprint and have not been substituted. Exact chip distributor sourcing
cannot yet be verified because official `ksmk.st.com` and `estore.st.com`
requests receive proxy CONNECT403. See the continuation evidence below and
[network prerequisites](cloud/ENVIRONMENT.md).

Current public native Circuit JSON was anonymously rechecked: all three mirrors
retain the reviewed SHA256. Purchased imports, component placements, CAD and
canonical copper remain unchanged by the isolated routing trials. Evidence:
`evidence/rev-0.0.41-alpha.0/continuation-20261006/`.

Reviewed 2026-10-06 against canonical native Circuit JSON
`e3564bef28127cda269198701137dd2be9b552f6418f82ebc407435d66018430`.
This is additional evidence for the existing revision. No canonical source,
supplier definition, saved route, dependency, Circuit JSON or Gerber is changed.

## Results

| Item | Actual result | Action still required |
| --- | --- | --- |
| Connections | 82/82 physical networks joined; zero native errors, opens, dangling items or shorts; zero strict geometry violations | Recheck after any adopted layout change |
| Standard JST programmer | Existing 38 physical-pin/net assertions pass; target USB-C powered, VOUT disconnected | Firmware and physical flash/verify/recovery tests |
| Vias | 224 through vias, zero blind/buried; 158 × 0.30/0.60, 63 × 0.20/0.38, 3 × 0.15/0.38 mm hole/pad | Actual topology changes to meet the requested uniform 0.30/0.45 dimensions; retain drill/track/pad checks |
| Power layers | Four motor nets and V3V3 still have inner-layer traces; 20 inner power pour regions | Actual outer-layer routing, with full connectivity/geometry requalification |
| Owned connector text | Pass: 0.198 mm pen and 0.214466 mm minimum mask clearance | No change needed for these four labels |
| Supplier silk | 541 native paths below 0.15 mm; top ink outside outline and both sides inside required mask clearance | Verified released importer/exporter repair; no hand-patched supplier definitions or generated CAM |
| Assembly orientations | J_USB, LED_POWER, LED_STATUS, LED_FAULT still unverified by native exporter | Verified supplier rotation metadata or assembler-approved CPL |
| Q_PD C2965326 | Fresh official JLC shop now lists genuine ST STL11N3LLH6: stock 100, displayed presale number 97 | Order-specific assembler acceptance and allocation; no replacement needed solely for the earlier missing shop result |
| U1 C2847904 | No exact official shop match; STM32G0B1CBT6TR also absent; related LQFP48 CBT3 stock zero | Exact-part sourcing or a separately approved footprint/layout change; stocked QFN48 is a different footprint |

The production silkscreen checker deliberately exits **1**. The fabrication
gate report deliberately exits **1** because measured and external gates remain
unapproved. Those exits are blockers, not successful qualification. The native
front/back silk renders were viewed; measurements use strict native Gerber
vectors, rather than drawing appearance alone.

## Motor copper and minimum thickness

`scripts/review-motor-copper-loss.py` checks all four real driver/connector
physical-pin endpoints and each actual nonzero segment. It ignores beneficial
parallel pads/pours and charges a full 1.716 mm barrel for every distinct used
via. At the existing 0.3424477 A phase peak, -20% finished width, uniform 80 °C
copper, assumed 35/15.2 µm outer/inner copper and uniform 18 µm hole plating:

| Phase | Two-lead series resistance bound | Peak drop | Peak copper loss |
| --- | --- | --- | --- |
| A | 0.239944 Ω | 0.082168 V | 0.028138 W |
| B | 0.379950 Ω | 0.130113 V | 0.044557 W |

Simultaneous peak loss bound is **0.072695 W**, excluding driver/shunts/motor and
other board circuitry. This is a DC analytical bound under assumptions, not a
predicted temperature or a guaranteed manufactured-board bound. Barrel loss is
at most 0.23842 mW per used hole under the same assumptions.

Inverting the retained IPC-2221 30 °C current screen requires **14.8254 µm minimum
inner copper** for the 0.27 mm nominal motor tracks at -20% width. The assumed
15.2 µm is only 2.53% above that thickness requirement. The manufacturer must
confirm a minimum, rather than an average or nominal weight. The corresponding
outer requirement for the 0.15 mm motor segments is 10.2581 µm under that model.
This does not qualify rail/ground pour necks, simultaneous branch sharing,
switching-loop inductance, device junction temperatures or IPC-2152 behavior.

## Rejected outer-layer trial

A fresh isolated native manual-source candidate moved only the MOTOR_A2 inner2
span to bottom, retaining its XY route, widths, ports and through barrels. It
completed within 56.2 s using a peak sampled 1,455.9 MiB. Native DRC found **13
errors** and independent geometry found **25 violations**, including U9 GND/V+
pads, V3V3, TEMP_ALERT_N and TMC_DIR contacts. The candidate is rejected and its
source delta, complete generated JSON, geometry and run status are retained.

Read-only manual corridor probes also found obstacles in alternative top and
bottom corridors; they are not native-qualified routing solutions. These trials
do not prove that no solution exists. Meeting outer-only power routing needs
coordinated signal/feature routing changes; changing a layer name alone is unsafe.
The earlier uniform-via and native Pipeline9 failures remain preserved.

## Toolchain review

Latest checked releases are core 0.0.2097, CLI 0.1.2253, checks 0.0.241, props
0.0.689, EasyEDA importer 0.0.371 and Gerber exporter 0.0.112. Core adds multiple
PCB paths; other new changes update dependencies. No relevant supplier
silkscreen clipping/width or assembly-rotation repair was found. The already
checked pinned toolchain is retained. A version bump alone would not repair the
current fabrication defects.

## Concrete manufacturer/assembler review request

This is a prepared checklist, **not a sent request or an order**. Supply the
existing immutable `NATIVE-REVIEW-GERBERS.zip`, `REVIEW-BOM.csv`, native CPL and
`FABRICATION-GATES.json` after layout/import defects have been repaired.

1. Confirm exact JLC04161H-3313 four-layer construction, finished thickness and
   tolerance; guarantee minimum inner/outer copper and minimum barrel plating.
2. Confirm all 66 individually named filled/capped features against
   `src/routing/filled-signal-vias-trial.json` and `thermal-vias-trial.json`.
   Require IPC-4761 Type VII epoxy fill/copper cap and ENIG as specified;
   recognize the isolated eFuse RTN exposed pad separately from GND.
3. Confirm solder mask/paste and soldering of exposed pads, clear board outline
   and production silkscreen. Existing supplier silk failures are unresolved.
4. Approve polarity and absolute CPL rotations for the four named parts against
   actual supplier reels and footprints. Native fallback PCB rotation is not
   supplier approval.
5. Obtain actual acceptance/allocation for all **108 fitted references / 42
   fitted part codes** (43 codes including R50 DNP). Ask whether exact genuine ST
   STM32G0B1CBT6 C2847904 can be obtained through global sourcing; do not approve
   a clone, different package or unreviewed ordering suffix. Q_PD C2965326 now
   has a positive public shop listing, but no stock has been reserved.

Evidence: `evidence/rev-0.0.41-alpha.0/{MOTOR-COPPER-LOSS,FABRICATION-GATES,
SILKSCREEN-CAM,REMAINING-PART-SEARCH,RELEASE-FIX-REVIEW,
REJECTED-OUTER-A2-TRIAL}.json`, with complete rejected geometry/JSON compressed
alongside. The owned-text fixture and its native Gerbers are retained for
independent reproduction.

**PROTOTYPE FABRICATION READY: NO.** No fabrication order, assembler approval,
firmware operation, physical programming, ESD/USB/power/thermal or motor test is
claimed.

Repeat the new reviews from the repository root:

```sh
python3 scripts/review-motor-copper-loss.py dist/index/circuit.json \
  evidence/rev-0.0.41-alpha.0/TRACE-WIDTH-AUDIT.json \
  evidence/rev-0.0.41-alpha.0/POWER-CORNER-SCREEN.json \
  evidence/rev-0.0.41-alpha.0/MOTOR-COPPER-LOSS.json
python3 scripts/review-fabrication-gates.py dist/index/circuit.json \
  evidence/rev-0.0.41-alpha.0 evidence/rev-0.0.41-alpha.0/FABRICATION-GATES.json
```

The second command is expected to exit 1 while the reported blockers remain.

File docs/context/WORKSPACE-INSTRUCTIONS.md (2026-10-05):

# tscircuit store board workspace

## Purpose and task isolation

This workspace is for designing and validating boards for the existing tscircuit
store. Work on board designs; do not rebuild the store application unless asked.

- Every new task/thread must work in a separate directory under
  `boards/<board-slug>--<unique-task-id>/`. Choose a descriptive lowercase,
  hyphenated board name and a unique task suffix before creating files.
- Follow-up messages in the same task continue in that task's directory. A new
  task continuing an existing board must use its own directory and record the
  source board directory and revision it started from.
- Keep each task's circuit sources, components, dependencies, configuration,
  tests, snapshots, build output and fabrication files inside its directory.
  Run board commands from that directory, never from the workspace root.
- Do not modify another task's directory or overwrite its generated files.
  Change shared workspace instructions only when the task calls for it.
- Use `index.circuit.tsx` as the board entry point. Keep a board `README.md` for
  usage and a `VALIDATION.md` for requirements, evidence and stage status.

## Publish every implementation step and version

- After every completed board implementation step and every new board version,
  commit the task's changes, push them to its configured GitHub repository and
  branch, and publish the same board revision to its configured tscircuit
  package using the supported publishing workflow.
- This is standing user authorization for these GitHub pushes and tscircuit
  publications. Do not request permission again for each step or version.
- Every board's GitHub repository and tscircuit package must be **public**.
  Create new board repositories and packages with public visibility. For an
  existing destination dedicated to the board, this is standing authorization
  to make it public; do not change the visibility of unrelated repositories or
  packages.
- Before publishing, run the checks applicable to the current implementation
  stage and record their results. Intermediate revisions must be labeled as
  work-in-progress prototypes, with unfinished stages and limitations clearly
  documented. Publication does not mean fabrication approval or hardware testing.
  Do not enable routing early, bypass checks or hide failures to publish a step.
- Give each implementation step a descriptive commit message and record the
  board revision and completed step in `VALIDATION.md`. Keep the GitHub source
  and tscircuit package contents consistent; do not publish unrelated task files
  or credentials.
- Include the generated circuit JSON in every published build. Rebuild it from
  the same source revision being published, commit and push
  `dist/index/circuit.json` to GitHub, and include the corresponding circuit JSON
  in the tscircuit package build through the supported publishing workflow.
  If the toolchain uses a different output path, record and use that actual path.
  Ensure ignore rules do not exclude this required artifact. Never hand-edit
  circuit JSON or publish stale output; preserve the routing state required by
  the current validation stage.
- Verify both remote updates succeeded and report the GitHub commit link and
  tscircuit package link, including the published version or revision identifier
  when available. Verify that both destinations are public and accessible
  without signing in. Record visibility verification in `VALIDATION.md`.
  Verify that both published builds contain the circuit JSON matching the
  validated local build; missing or mismatched circuit JSON is a blocking issue.
  A local commit or a private publication does not complete this requirement.
- If the destination repository, branch or package is unknown, or validation,
  authentication, pushing, publishing or public-visibility verification fails,
  report a **blocking issue** with
  the exact missing information or failure. State which remote updates succeeded
  if only one succeeded; do not claim the step is fully published.
- This authorization covers board pushes and package publications; merging pull
  requests and placing fabrication orders require their own user authorization.

## Mandatory JLCPCB component imports

**NOTE: Never use custom components or create component definitions. All
electronic components must be imported from JLCPCB.**

- Use the supported JLCPCB import workflow and record each component's exact
  JLCPCB/LCSC part number.
- Do not hand-create, recreate or manually patch component symbols, footprints,
  pin mappings or imported component definitions. Do not replace a failed import
  with a generic component, placeholder or locally authored substitute.
- If a required part cannot be imported, or an imported component has any issue,
  report it to the user explicitly as a **blocking issue**. Include the part
  number, the error or discrepancy, and the affected validation stage. Record
  the blocker in `VALIDATION.md` and stop dependent work; do not work around it
  by creating or modifying a component.
- Board structure, wiring, schematic sheets and PCB features such as mounting
  holes remain native tscircuit elements; they are not purchased components.

## Schematic sheets and sections

- Every board must use native tscircuit schematic sheets in A4 format.
- Use schematic sections only when a sheet is complicated and grouping related
  circuitry into labeled functional blocks improves readability. Simple sheets
  should remain without sections.
- Keep symbols, wiring, labels and sheet information readable within the A4
  boundary. Use additional A4 sheets when needed rather than crowding a sheet.
- Verify the supported sheet and section APIs in the installed tscircuit
  version, and inspect the rendered sheets during schematic validation.

## Validation record and gates

Validate every new board through the stages below, in order. Record each stage
as `not started`, `in progress`, `blocked` or `passed` in the board's
`VALIDATION.md`. Include the board revision, source commit when available,
dependency and CLI versions, commands and results, reviewed artifact paths,
datasheet references, accepted warnings and unresolved issues. If Git is not
available, preserve a versioned source and dependency manifest with checksums
so that evidence identifies the exact design that was checked.

Do not mark a check as passed without running it or a visual review as complete
without inspecting the output. Missing requirements, unavailable checks and
unperformed physical tests must remain explicit. Resolve blockers before
claiming the corresponding stage is complete.

Use the board project's configured formatting, TypeScript and test commands.
Verify CLI support using the installed version's help or official source. The
commands below are required checks; if one is unavailable or incompatible,
record the blocker and resolve the tooling issue instead of silently skipping
it, substituting a weaker check or claiming success.

### 1. Confirm requirements

Record the intended function, supply voltage, current limits, interfaces, board
dimensions, mounting arrangement, layer count and target manufacturer's
capabilities. Include the applicable trace width, clearance, drill, via and
stackup limits. Identify assumptions and resolve design-critical unknowns
before relying on them.

### 2. Review the schematic and BOM

Verify connections against manufacturer datasheets: pin numbers, power rails,
component values, protection, decoupling, startup states and unused pins.
Verify exact part numbers, packages, footprints, polarity and supplier
availability. Record datasheet links and the date of availability checks.

### 3. Validate placement before routing

Keep routing disabled until connectivity, BOM and placement are checked. Use
the installed tscircuit version's supported routing controls and verify that
the placement output is unrouted.

Inspect component bodies, courtyards, connector access, test-point access,
mounting clearances and mechanical fit.

Run from the task's board directory:

```sh
tsci check netlist index.circuit.tsx
tsci check pin_specification index.circuit.tsx
tsci check source index.circuit.tsx
tsci check schematic-placement index.circuit.tsx
tsci check placement index.circuit.tsx
```

Resolve connectivity, BOM and placement issues before enabling routing.

### 4. Route and validate the generated copper

Enable native routing, build the board and verify:

- Every required connection is physically routed.
- There are no shorts, disconnected segments or copper crossing keepouts.
- Actual trace widths, clearances, via dimensions and layer spans meet the
  recorded requirements.
- Power paths and their narrow sections support the intended current.
- Ordinary drills clear component and test pads, including same-net cases.
- Intentional thermal vias or other exceptions are explicitly identified and
  reviewed.

Inspect generated geometry; configuration values alone do not prove compliance.
Record measured dimensions and the basis for current-carrying limits for
critical paths.

### 5. Run automated and visual checks

Run formatting, TypeScript checks and meaningful board tests. Check the routed
output:

```sh
tsci build index.circuit.tsx --pcb-png --pcb-svgs --schematic-svgs
tsci check shorts dist/index/circuit.json
tsci snapshot index.circuit.tsx
```

Confirm that the output being checked was generated from the current source
revision with routing enabled. Inspect the schematic, each copper layer and
detailed views of critical areas. Review snapshot changes before accepting them.

Require zero unresolved errors. Fix actionable warnings; document the reason
for accepting any remaining warning. Do not hide failures, weaken checks,
suppress violations or accept snapshots merely to obtain a passing result.

### 6. Approve prototype fabrication

Generate Gerbers, drill files, BOM and placement files from the same validated
revision. Review stackup, holes, slots, board outline, solder mask, paste,
component orientation and assembler feedback. Keep the fabrication package
linked to the source revision and validation evidence.

Passing this stage means **ready to order a prototype**. It does not mean the
physical hardware has been tested. Report this status without placing an order
unless the user has explicitly authorized ordering.

### 7. Test the physical prototype

Verify assembly, mechanical fit, power-up, programming, interfaces, sensors and
the intended load. Measure relevant current, voltage and temperatures. Test
applicable protection and fault behavior.

Record the physical board revision, assembly configuration, firmware versions,
test setup, operating conditions, measurements, results and failures. Obtain
actual physical test evidence; automated design checks or simulations do not
complete this stage. If no prototype is available, leave this stage pending
and identify the design as an untested prototype.

### 8. Prepare the store release

Include a descriptive name, revision, pinout, supported operating limits,
usage instructions, photos, test results and known limitations. Ensure the
published package builds and matches the validated revision. Distinguish
intended limits from limits verified by physical testing.

Label untested designs as **prototypes**. An explicitly labeled prototype
release may be prepared while stage 7 remains pending; it must disclose the
missing physical tests and must not imply that all validation stages passed.
Claim **hardware tested** only for the configuration and operating conditions
actually tested. Do not present rendered images as physical prototype photos
or invent test results.

Revalidate affected areas after design or dependency changes, including new
fabrication outputs when the validated design changes. Record which earlier
results remain applicable and why. Publish each completed implementation step
and version under the standing authorization in "Publish every implementation
step and version" above, preserving the prototype labels and validation gates.

## GitHub authentication

- Use the configured GitHub account `AnasSarkiz` for GitHub operations unless
  the user explicitly requests another account.
- Prefer the authenticated GitHub app connector for pull-request, issue,
  review and repository API actions.
- On macOS, sandboxed commands may be unable to read GitHub CLI credentials
  stored in Keychain. If `gh auth status` fails inside the sandbox, retry with
  escalated sandbox permissions before concluding that authentication is invalid.
- Run authenticated `gh` commands and Git network operations with the narrowly
  scoped escalated permissions needed for Keychain and network access.
- Ask for reauthentication only if the escalated `gh auth status` check also
  fails.
- Keep GitHub credentials in macOS Keychain. Never print, copy or persist tokens
  in prompts, repositories, environment files or plaintext configuration.

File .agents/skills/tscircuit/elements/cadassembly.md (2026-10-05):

# `<cadassembly />`

A CAD assembly is a collection of cad models and constraints to "put together" a component.

## Example

```tsx
export default () => (
  <board width="10mm" height="10mm">
    <chip
      name="J1"
      cadModel={
        <cadassembly>
          <cadmodel
            positionOffset={{ x: 0, y: -4, z: 0 }}
            rotationOffset={{ x: 0, y: 0, z: 0 }}
            modelUrl="https://modelcdn.tscircuit.com/jscad_models/pinrow4.glb"
          />
          <cadmodel
            positionOffset={{ x: 0, y: 4, z: 0 }}
            rotationOffset={{ x: 0, y: 0, z: 0 }}
            modelUrl="https://modelcdn.tscircuit.com/jscad_models/pinrow4.glb"
          />
        </cadassembly>
      }
    />
  </board>
)
```

## Props

Commonly used: `originalLayer`, `children`, `name`, `footprint`, `connections`

## References

- Props: [CadAssemblyProps](https://github.com/tscircuit/props#cadassemblyprops-cadassembly)
- Source: [lib/components/cadassembly.ts](https://github.com/tscircuit/props/blob/main/lib/components/cadassembly.ts)
- Local docs: [docs/docs/elements/cadassembly.mdx](../docs/docs/elements/cadassembly.mdx)

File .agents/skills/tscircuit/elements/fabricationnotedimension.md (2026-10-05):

# `<fabricationnotedimension />`

Dimension callout drawn on the fabrication layer.

## Example

```tsx
export default () => (
  <board width="20mm" height="15mm">
    <fabricationnotedimension
      from={{ x: -4, y: 0 }}
      to={{ x: 4, y: 0 }}
      fontSize={1.2}
      arrowSize={0.8}
    />
  </board>
)
```

## Props

Commonly used: `from`, `to`, `text`, `offset`, `font`, `fontSize`, `color`, `arrowSize`

## References

- Props: [FabricationNoteDimensionProps](https://github.com/tscircuit/props#fabricationnotedimensionprops-fabricationnotedimension)
- Source: [lib/components/fabrication-note-dimension.ts](https://github.com/tscircuit/props/blob/main/lib/components/fabrication-note-dimension.ts)

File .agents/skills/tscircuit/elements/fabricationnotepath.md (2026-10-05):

# `<fabricationnotepath />`

Polyline/path annotation on the fabrication layer.

## Example

```tsx
export default () => (
  <board width="20mm" height="20mm">
    <fabricationnotepath
      strokeWidth={0.3}
      route={[
        { x: -5, y: 0 },
        { x: 0, y: 5 },
        { x: 5, y: 0 },
      ]}
    />
  </board>
)
```

## Props

Commonly used: `pcbLeftEdgeX`, `pcbRightEdgeX`, `pcbTopEdgeY`, `pcbBottomEdgeY`, `pcbX`, `pcbY`, `pcbOffsetX`, `pcbOffsetY`

## References

- Props: [FabricationNotePathProps](https://github.com/tscircuit/props#fabricationnotepathprops-fabricationnotepath)
- Source: [lib/components/fabrication-note-path.ts](https://github.com/tscircuit/props/blob/main/lib/components/fabrication-note-path.ts)

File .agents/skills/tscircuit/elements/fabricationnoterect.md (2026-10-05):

# `<fabricationnoterect />`

Highlight fabrication callouts and assembly regions with rectangular annotations on the fabrication layer.

## Example

```tsx
export default () => (
  <board width="28mm" height="20mm">
    <resistor name="R1" resistance="1k" footprint="0603" pcbX={-6} pcbY={-2} />
    <capacitor name="C1" capacitance="1uF" footprint="0603" pcbX={-2} pcbY={2} />
    <fabricationnotetext
      text="Install last"
      pcbX={5}
      pcbY={2}
      anchorAlignment="bottom_left"
      fontSize="1.4mm"
    />
    <fabricationnoterect
      pcbX={0}
      pcbY={0}
      width={18}
      height={12}
      strokeWidth={0.3}
      color="#2563eb"
      hasStroke
    />
  </board>
)
```

## Props

Commonly used: `width`, `height`, `strokeWidth`, `isFilled`, `hasStroke`, `isStrokeDashed`, `color`, `cornerRadius`

## References

- Props: [FabricationNoteRectProps](https://github.com/tscircuit/props#fabricationnoterectprops-fabricationnoterect)
- Source: [lib/components/fabrication-note-rect.ts](https://github.com/tscircuit/props/blob/main/lib/components/fabrication-note-rect.ts)
- Local docs: [docs/docs/footprints/fabricationnoterect.mdx](../docs/docs/footprints/fabricationnoterect.mdx)

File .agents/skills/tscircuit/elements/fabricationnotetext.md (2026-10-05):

# `<fabricationnotetext />`

The `<fabricationnotetext />` element adds fabrication layer callouts and build notes for assemblers.

## Example

```tsx
export default () => (
  <board width="24mm" height="18mm">
    <resistor name="R1" resistance="10k" footprint="0402" pcbX={-5} pcbY={0} />
    <led name="D1" footprint="0603" pcbX={5} pcbY={0} />
    <fabricationnotetext
      text="Install connector last"
      pcbX={0}
      pcbY={6}
      fontSize="1.6mm"
      anchorAlignment="top_left"
      color="#d97706"
    />
  </board>
)
```

## Props

Commonly used: `text`, `anchorAlignment`, `font`, `fontSize`, `color`, `name`, `footprint`, `connections`

## References

- Props: [FabricationNoteTextProps](https://github.com/tscircuit/props#fabricationnotetextprops-fabricationnotetext)
- Source: [lib/components/fabrication-note-text.ts](https://github.com/tscircuit/props/blob/main/lib/components/fabrication-note-text.ts)
- Local docs: [docs/docs/footprints/fabricationnotetext.mdx](../docs/docs/footprints/fabricationnotetext.mdx)

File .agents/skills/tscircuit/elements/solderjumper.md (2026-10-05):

# `<solderjumper />`

Small pads that can be cut or bridged with solder for configuration options.

## Example

```tsx
export default () => (
  <solderjumper name="SJ1" footprint="solderjumper2_bridged12" bridgedPins={[["1","2"]]} />
)
```

## Props

Commonly used: `bridgedPins`, `bridged`, `name`, `footprint`, `connections`

## References

- Props: [SolderJumperProps](https://github.com/tscircuit/props#solderjumperprops-solderjumper)
- Source: [lib/components/solderjumper.ts](https://github.com/tscircuit/props/blob/main/lib/components/solderjumper.ts)
- Local docs: [docs/docs/elements/solderjumper.mdx](../docs/docs/elements/solderjumper.mdx)

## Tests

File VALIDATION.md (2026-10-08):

# Active routing — 0.0.53-alpha.0

Read `docs/REV53-LOGIC-POWER-ESCAPES.md`. The canonical native replay retains
all56/120 complete nets, with240 required opens,128 tracks,82 ordinary0.30/0.45mm
full through vias,five manifested TypeVII thermal vias and seven filled regions.
Native other-errors:0; unchanged strict and filled-copper clearance failures:0;
GND remains one physical network. Original purchased definitions, all165 fitted
model transforms, capacitor placement, motor and carrier are preserved.
The complete USB_VDD bypass/return geometry is screened; V3V3 remains incomplete.
Continue3.3V/core power,PD/eFuse controls,USB pair and ALL remaining physical nets.
Publication is WIP; loaded power/USB/thermal,complete CAM,quote and hardware tests
remain pending. Do not stop at this step. PROTOTYPE FABRICATION READY:NO.

Revision53's same-source native CLI build completed in59.47seconds with240
opens only. Three canonical Circuit JSON mirrors match SHA-256`69cb21a1bf916829317d38fc030a85cb0812607d69204dfe7ab4e31a08c6ac6d`.
Strict copper,all120 physical-net/filled-clearance checks,USB decoupling geometry,
five thermal owners,programmer pin mapping,interlock truth/static corners,
166notes/11A4 sheets and seven synthetic PDO tests pass their stated scopes.
Same-source schematic-only draft pin checks,format,TypeScript and frozen319-package
install pass. All165 fitted transforms/asset URLs remain exact. Required CLI
checks report0netlist/source/pin errors,23source and35pin warnings;one retained
D_VBUS schematic rotation finding;six orientation suggestions,zero native
placement DRC. Source automatic datasheet lookups remain403; retained genuine
manufacturer pin/datasheet reviews are independent. Exact public publication
passed: implementation377c9515dd0a311783a5db1ff1395c53010079f6 and public tscircuit0.0.53-alpha.0 release37065d22-1a1c-4c96-8927-f75a9dd03d62 each have838 exact HTTP200 anonymous checksum records in evidence/rev-0.0.53-alpha.0/PUBLICATION.json. The checksummed Circuit JSON is69cb21a1bf916829317d38fc030a85cb0812607d69204dfe7ab4e31a08c6ac6d. Stage4/5/6 and hardware validation remain incomplete. Continue routing.

---

# Revision 0.0.52-alpha.0 — protected VBUS and VM connected

**PROTOTYPE FABRICATION READY: NO. Routing continues; hardware tests pending.**

The native power019 replay physically joins all protected-VBUS and all fifteen
VM terminals, preserving every prior54 complete net. 56/120 nets complete,265
open ports,112 tracks,79 ordinary full through0.30/0.45mm vias,five unchanged
manifested TypeVII thermal vias,eight native filled regions. Native errors other
than opens:0; unchanged strict copper/drill and filled-copper violations:0.
GND remains one physical network. All four actual copper layers were viewed.
Five previous source paths change to clear power escapes;82/87 remain exact.
Official purchased footprints/models/placement/electrical pin partitions remain
unchanged. The native inner2 VM plane and one ordinary ground stitch cost no
extra layers. Short terminal leads require loaded current review; no hardware
or complete routing claim. Accepted source paths freeze before new phase3
selected-net routing. Failed candidates are preserved as unqualified evidence.

Fresh isolated native CLI build completed in68.3seconds and reproduces the
qualified native copper exactly. Three canonical JSON mirrors match SHA-256
`6ce4133d8c7ae11d6cf7aa9c90e90893a18175516f507eb7122a462654a991ef`. Strict copper,all120 physical-net tests,thermal-owner
guard,38 programmer pin checks,16 interlock truth/static corners,166 schematic
notes/11A4 sheets,seven synthetic PDO tests,format/TypeScript/frozen lockfile
and CLI shorts pass their stated scopes. All165 fitted model transforms/assets
remain exact. Required CLI stage checks ran:0netlist errors;0pin/source errors
with35/23 retained warnings;one unchanged imported D_VBUS schematic rotation
suggestion;six orientation suggestions and zero native placement DRC.
No total-board clean result is claimed. Stage4/5/6 remain in progress.
Public WIP publication verified at2026-10-07T23:08:01.175Z. Source commit
`cf5e21862549243ef36da926d338904cbc8936d2`,release`f1f1e3f0-735d-4eac-b04d-6e000382af50`.
All815 package files and815 immutable GitHub files match exact frozen-packet
checksums anonymously. Circuit JSON SHA-256 is the value above; every original
referenced CAD asset is included. ready_to_build:true,hosted build/hardware
success not claimed. Receipt:`evidence/rev-0.0.52-alpha.0/PUBLICATION.json`.
Routing continues. New logic candidates are unqualified until full replay. See [REV52-VM-POWER-ROUTING.md](docs/REV52-VM-POWER-ROUTING.md).

---

# Revision 0.0.51-alpha.0 — checked FET-source copper and direct thermal vias

**PROTOTYPE FABRICATION READY: NO. Routing continues; no physical hardware test.**

Power059 qualifies54/120 physical nets with291 open ports,87 tracks,66 ordinary
0.30mm drill/0.45mm pad full through vias,five manifested TypeVII filled/capped
thermal vias under the original TMC2209 EP,and six filled GND regions. All prior
53 complete nets survive; GND and the seven FET-source terminals each form one
physical network. Native replay exits1 solely for291 required opens; zero other
native errors,strict copper/drill violations or filled-copper clearance failures.
All four rendered copper layers were viewed. Evidence and source provenance:
`evidence/rev-0.0.50-alpha.0/routing/power059-replay/QUALIFICATION-SUMMARY.json`.

The failed full-board/source/gate candidates remain explicitly unqualified.
Native Pipeline9's local bounds change preserves every original obstacle and
rule; its full solve completed in202seconds before full-board manual repair.
Only three saved gate paths were replaced;78 prior paths remain exact. Six source
paths complete PD_FET_SOURCE. Supported source paths alone changed; no supplier
or generated Circuit JSON edits. The five exact U2.29 owner contacts pass the
re-enabled official via-in-pad guard; ordinary contacts remain disallowed.
Loaded power/USB/thermal,fresh complete CAM,assembly quote and live stock
allocation remain pending. Filling/capping cost is unquoted.

The synthetic STUSB readback regression now verifies a genuine invalid20V/1.5A
PDO2 word0x00064096 before asserting rejection. All seven synthetic cases pass;
this is reproducible validator evidence,not physical NVM readback.

Fresh canonical CLI build has SHA-256
`eaa2bec0cc85443567b72e08e0f7644c6c43eb26d7217d15c96c767364306450`;
all three mirrors match. Copper/net geometry exactly matches qualified power059;
only generated IDs/endpoint annotations differ. Native build exits1 solely for
291 opens. Fresh unchanged strict copper and all120 physical-network checks
confirm54 complete and zero clearance failures. The official shorts check passes.
Unrouted source netlist has0 errors/0 warnings and its172 purchased-pin partitions
exactly equal canonical copper. Correctly unrouted draft checks,166 purpose notes,
both standard USB symbols,38 programmer checks and16 interlock truth/static-corner
checks pass. Formatting,TypeScript and frozen lockfile verification pass.

Pin/source checks report0 errors with35/23 attribute/source warnings. Schematic
analysis retains the original D_VBUS rotation finding; placement exits1 for six
orientation suggestions with0 native diagnostic errors. These are explicitly WIP
and will be reviewed before final qualification. Current165 fitted CAD transforms
and all original asset bytes exactly match the qualified two-port actual assembly.

The initial publication packet omitted three historical import modules needed by
the unchanged pin audit. Their original modules/assets are now included; the
exact build and pin audit passed that dependency stage. The early draft test was
invoked against routed geometry and correctly rejected it; a fresh --disable-pcb
draft passes. Original failure/repair records remain explicit.

Matching public GitHub/tscircuit publication completed at2026-10-07T21:37:26.097Z.
Implementation commit`6919a5874da51a3c359b4b700aea453fdeaf3026` and public release
`1b8346be-2413-4489-8ab5-606ceadd5161` contain revision0.0.51-alpha.0. All742 package
files and all742 immutable GitHub files passed anonymous exact-byte SHA-256
verification, including the three canonical Circuit JSON mirrors and every
referenced original CAD dependency. The release reports ready_to_build:true;
hosted build success is not claimed. Receipt:
`evidence/rev-0.0.51-alpha.0/PUBLICATION.json`. Routing continues from the accepted
54/120-net baseline; later power candidates remain unqualified until checked.
Prior public revision50 receipts below remain valid.
See [the current routing record](docs/REV51-POWER-THERMAL-ROUTING.md).

---

# Revision 0.0.50-alpha.0 — two-port WIP implementation

**PROTOTYPE FABRICATION READY: NO. No hardware testing or fabrication order.**

Public WIP verification completed at 2026-10-07T19:34:23.454Z. GitHub implementation
commit `d7089622defe6dc29d253f82c185fa972aab5e5a` and public tscircuit release
`d40636fb-e07c-4c37-928c-be6136b5537f` contain matching revision0.0.50-alpha.0. All715
package files and all715 immutable GitHub files passed anonymous SHA-256
verification, including the three canonical Circuit JSON mirrors and115 original
local CAD assets. No referenced CAD asset is omitted. The official release
reports ready_to_build:true; hosted build/3D-render success is not claimed.
See `evidence/rev-0.0.50-alpha.0/PUBLICATION.json`. Routing continues.

RP2040, STUSB4500 and MCP2515 remain selected. Separate official USB-C POWER
and DATA connectors, 15 V NVM programming/readback procedure, isolated computer
VBUS sensing and hardware motor interlock are implemented. Active requirements
and qualification scope are in [REV50-TWO-PORT-ROUTING.md](docs/REV50-TWO-PORT-ROUTING.md).

The fresh native CLI canonical JSON has SHA-256
`88d464e298e7194c9e02f2b7e8bfce4fc0bb1954a5d70f8daff16cd335f70df6`.
All three canonical mirrors match. Its checked power038 baseline has 53/120
physical networks complete, 298 open ports, 81 tracks, 62 ordinary 0.30/0.45 mm
through vias and six filled GND regions. All twelve raw PD VBUS terminals and
GND each form one physical network. Every required network was physically
inspected; the remaining 67 remain failures. Strict copper and filled-copper
clearances pass unchanged, as does the official all-layer shorts check.
Native canonical build exits 1 solely for the 298 opens.

Stage 1 requirements and Stage 2 exact imported identities/manufacturer pin
review are recorded; customer stock allocation/PCBA quote remain pending.
Stage 3 static assembly/model/carrier/cable checks pass for 165 fitted models,
with bounded cable-envelope assumptions. Official schematic analysis leaves
one unchanged imported TVS orientation finding. CLI placement retains six
orientation suggestions and exits 1; it reports zero native placement errors.
Stage 4 routing is in progress. Stage 5 loaded power/USB/thermal and complete
fresh CAM remain incomplete. Stage 6 NVM/hardware/programming tests are pending.

The coherent lockfile pins Bun1.3.9, tscircuit0.0.2757, CLI0.1.2257, core0.0.2107,
router0.0.962, props0.0.695, checks0.0.242, circuit-json0.0.520, svg0.0.445 and
easyeda0.0.374. Formatting and TypeScript checks pass. Critical imported pins,
the unrouted draft's explicit two-port pin/net isolation checks, both standard
USB-C schematic symbols, 166 purpose notes, motor-interlock static corners and
38 standard-JST-programmer wiring checks pass. Physical flashing is untested.

Mandatory CLI inspection uses the exact native canonical Circuit JSON where
supported. Netlist inspection uses the explicit unrouted source preview: zero
errors/warnings, with every electrical source partition identical to canonical.
Direct routed-source netlist logs preserve the released PCB-disabled routing
update error; it was not suppressed or claimed successful. Pin specification
has zero errors/35 warnings; source has zero errors/23 warnings, including
external datasheet lookups and the branched reversible USB pair. Actual USB
pair geometry/return-path qualification remains required. The build also
discloses an optional autorouting-cache serialization warning for Q_BUZZ;
qualified source paths and actual emitted copper remain independently verified.

Evidence is in `evidence/rev-0.0.50-alpha.0/CANONICAL-*`, `CLI50-*`,
`BAT54WS-TP-QUALIFICATION.json`, the actual assembly audits and routing/power038.
Failed routing candidates are retained as unqualified; none is accepted copper.
The diode replacement fixes missing polarized schematic aliases using an
unchanged official import with identical original pad/model geometry. J_SWD's
bottom-side repair removes the verified DATA-port mating-envelope collision.
All four fresh copper renders and the updated interlock sheet were viewed.

This completed implementation step is authorized for public WIP publication
with this accepted copper baseline. Only an anonymous exact-byte receipt proves
publication; local version numbers or ready_to_build do not prove a hosted
build, hardware result or fabrication approval. Continue protected VBUS/common
FET source/VM, logic power, PD controls, USB and all remaining nets immediately
after this publication.

---

## Historical revision 48 record

# Routing checkpoint — 0.0.48-alpha.0, 2026-10-07

Public verification completed at 2026-10-07T14:29:42.731Z. GitHub main implementation commit
`91ab2a97bbe3bc41eac98e19b2dfe1f5c7032ac5` and public tscircuit release
`8ab4eea9-cdce-4c8c-b9cc-162bb01a0d2f` contain matching revision0.0.48-alpha.0. All309
package files and all309 immutable GitHub files pass anonymous exact SHA-256
verification, including fresh Circuit JSON and103 original local CAD assets.
The official release reports ready_to_build:true; no hosted build success,
hardware result or fabrication readiness is claimed. See
`evidence/rev-0.0.48-alpha.0/PUBLICATION.json`.

**PROTOTYPE FABRICATION READY: NO. Routing continues.**

Native source replay now connects 64/108 physical networks including all 118
GND endpoints. It contains 97 tracks, 79 ordinary 0.30 mm drill / 0.45 mm pad
through vias and eight native ground pours. Exactly 227 open-port errors remain;
there are zero other native errors or strict copper/drill/edge/keepout violations.
All 64 checked networks have one physical copper component. Fresh native canonical build and independent checks pass. All three canonical
Circuit JSON mirrors have SHA-256 `27223cf4894c1cbc9d50b5ddde6ab8624af220a0b3e3533779db90755855ef7a`. Publication byte verification
is recorded separately after upload; native build exits1 for these227 opens.

CAN SPI chip select and interrupt join both their MCU/driver pads and actual
pull-up pads. R_CAN_CS moves from bottom (2.25,-1.5), source rotation90, to
bottom (1.5,-0.2), rotation0, releasing the actual SPI escape corridor. The
nearby C31 stays at its original bottom (9.25,-1.25), rotation180. Source paths
repair MISO, SPI clock and crystal XOUT around these actual footprints. Earlier
failed placement/ground-isolation candidates are preserved.

The official native Pipeline9 public SDK fully solves seven programmer/ADC
connections in 307.49 seconds with a 6 mm maximum mesh node dimension, aspect
ratio30 and minimum node area0.01. Mesh construction/merging consumes about
219 seconds. Peak sampled routing RSS is7210.75 MiB. Its unchanged input and
complete output are preserved in routing/programmer090 and programmer102.
An initial native replay finds33 independent copper violations. Manual source
repairs move ordinary vias clear of real pads/annuli and adjust clock/reset
corridors; the final programmer121 replay passes every original spacing limit.
LED_FAULT_A is an additional manually saved three-layer source route. The
POWER_GOOD bottom trunk is shortened through the verified pad-free U7 interior.
No generated Circuit JSON, supplier footprint, dependency, DRC limit or type
check is edited. A solved router output alone is never a board qualification.

The new saved networks are CAN_SPI_CS, CAN_INT_N, SWDIO_CONN, SWCLK_CONN,
NRST_CONN, SWDIO_GUARDED, SWCLK_GUARDED, NRST_GUARDED,
VBUS_ADC_PRE_GUARD and LED_FAULT_A. One bounded Pipeline9 batch now addresses
three remaining motor windings and five motor-driver controls. Its unfinished
outputs remain separate from this checked revision.

Actual current CadQuery imports/reexports all12 IC models and146 fitted
component records (53 unique genuine STEP files). The actual mounted assembly
passes nominal146-mesh component/carrier clearance. No placeholder CAD or
supplier model edit is used. These reports cover the R_CAN_CS placement change;
subsequent copper-only changes require exact CAD-record equality. Supplier
stock/pricing snapshots remain those from2026-10-07 12:01UTC; no reservation or
assembler allocation is implied. The five-board fitted-part baseline remains
USD27.261 per board before PCB, assembly/loading/extended fees, losses/minima,
shipping/tax, carrier and motor.

All remaining44 networks, loaded widths/pad necks/thermal review, actual USB
via delay/coupling/reference/impedance, fresh CAM/BOM/CPL, assembly allocation
and delivered quote remain open. The disclosed imported D_VBUS schematic
rotation and three native component-orientation suggestions remain explicit.
The unchanged nine schematic sheets were viewed in revision46. Programmer
pin wiring, standard USB-C symbol groups and planar USB path limits pass fresh canonical checks. All four actual current layer PNGs were viewed;
TypeScript, native shorts, unchanged strict geometry and filled connectivity
pass. The full official style analyzer retains one imported D_VBUS finding. No physical programming, negotiation, motor test
or fabrication order is claimed. The exact14HM11-0404S, four connectors,
35x35 mm four-layer outline and front carrier are preserved.

Evidence: evidence/rev-0.0.48-alpha.0/; final qualified source replay
routing/programmer121/. Publication includes exact fresh Circuit JSON and all
unchanged original referenced CAD assets. Its completed receipt is recorded
only after anonymous package and immutable GitHub SHA-256 checks.

---

# Historical revision47 checkpoint

# Routing checkpoint — 0.0.47-alpha.0, 2026-10-07

## Exact revision47 publication verified

Source commit `b6388c51a8178cef35be6af1802654cabb2a59b3` and public tscircuit release
`ee327023-5e57-4b0f-96d5-8f2973ce475c` contain matching revision0.0.47-alpha.0. All308
package files and308 immutable GitHub files pass anonymous SHA-256 comparison
at 2026-10-07T13:02:58.263Z. Original103 local model assets are included.
Hosted ready_to_build is true; no hosted build success, physical test or
fabrication readiness is claimed. See evidence/rev-0.0.47-alpha.0/PUBLICATION.json.
Routing continues.

**PROTOTYPE FABRICATION READY: NO. Routing continues.**

Fresh native canonical Circuit JSON connects 54/108 physical networks, including
all 118 ground ports. It contains 85 tracks, 56 ordinary 0.30 mm drill / 0.45 mm
pad through vias spanning all four layers, nine native GND pours and 249 explicit
open-port errors. There are zero other native errors, zero native shorts and
zero strict copper/drill/edge/keepout violations. Each of the 54 selected nets
has exactly one independently measured physical copper component. All three
canonical JSON mirrors match SHA-256 `305f6abf833547bb1738e89fe3ea6429447a46542aa8d93aad74cc74ea3911da`.
The native builder correctly exits one for remaining missing connections.

Native Pipeline9 supplies CAN TX/RX candidates through its public
getNewTracesBeforePowerExpansion API. The original preliminary output and failed
replays remain preserved. Board-owned source paths repair sub-micron rounded
endpoints, move an illegal C20 via, clear an existing via, move a Q_ILIM escape
0.05 mm and reroute the crowded CAN pins. The existing reset top trunk moves to
y=-0.75 mm for both CAN and eFuse-via clearance. All spacing limits remain intact.
Native Pipeline9 continues its own full repair when a diagnostic candidate is
captured; a preliminary file never counts as solved or qualified. Current board
source adopts only the later checked can075 replay.

MOTOR_A1 is manually drawn entirely on TOP, with no extra via. Its initial 3 mm
escape is 0.30 mm wide for the unchanged sense-trace clearance; the remaining
outer path is 0.40 mm. Loaded current, pad necks, tolerance and thermal review
remain unfinished. The other three winding nets are not routed yet.

Input-only capture through the native core routing-start event avoids an entire
unsuitable default-mesh solve before an SDK mesh job. It preserves exact input
fields and coordinates, records the actual baseline and exits two because
routing is incomplete. This is a diagnostic tool change, not a substitute
router or a successful-board-build claim. SDK mesh choices do not alter any
board DRC limit. Candidates still need fresh native source replay, unchanged
strict geometry and all selected physical filled-net checks before adoption.

The 147 purchased references / 146 fitted / 54 exact supplier identities remain
unchanged from revision46. Actual revision46 CadQuery and nominal mounted-fit
results carry forward through exact equality of all 146 canonical CAD records;
no model or placement changed. Fresh official stock/pricing/SMT checks from
2026-10-07 12:01 UTC remain the last supplier snapshots, not assembler allocation.
The five-board fitted-parts baseline is USD27.261 per board before PCB,
assembly/loading/extended fees, losses/minima, shipping/tax, carrier and motor.
All 12 IC models are genuine; no placeholder or vendor import patch is used.

Fresh TypeScript/formatting, native shorts, independent canonical geometry and
filled connectivity pass. Programmer wiring passes 38 physical pin/net assertions;
VOUT is isolated. Standard USB-C represents all 16 purchased pin/pad groups.
Planar USB limits remain unchanged and pass: main trunk skew0.19510 mm,
MCU stubs0.09995 mm and both plug paths0.40879 mm. Branched USB DifferentialPair
properties still emit two explicit metadata warnings; the native Bus constrains
actual trunks while independent measurements constrain both full plug paths.
Via delay, coupling, real impedance/reference continuity remain separate gates.
All four actual layer images were viewed after these changes. The unchanged nine
schematic sheets were viewed in revision46. The full official style analyzer
still finds one unmodified D_VBUS rotation issue. Three native placement
orientation suggestions from revision46 remain explicit; no clean final
placement screen is claimed. Neither style disclosure nor future physical tests
excuses stopping independent PCB work.

All remaining 54 nets, power widths/returns/thermal, USB qualification, fresh
Gerber/drill/BOM/CPL/CAM, assembler allocation and delivered quote remain open.
The exact 14HM11-0404S, four connectors, 35 x 35 mm four-layer outline and carrier
are retained. No order, hardware test or fabrication approval is claimed.

Evidence: evidence/rev-0.0.47-alpha.0/; qualified source replay routing/can075/.
Publication requires matching fresh Circuit JSON and original CAD hashes;
its verification receipt will be recorded after public byte checks.

---

# Historical revision46 validation

# Routing checkpoint — 0.0.46-alpha.0, 2026-10-07
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

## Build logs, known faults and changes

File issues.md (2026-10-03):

# Current revision 16 issue disposition

Pre-routing requirements, paper schematic/BOM and placement design gates pass for the bounded untested prototype recorded in VALIDATION.md. B017's design-stage carrier/tolerance/mating screen is resolved by four direct rails and measured envelopes. B013's paper bootstrap/load and reverse-blocking review is resolved within the explicit PD/load limits. Physical performance, actual copper/HF layout, thermal paths, silkscreen, manufacturing outputs/CAM, firmware and prototype tests remain unfinished. B012 is the user-accepted cosmetic TVS symbol rotation defect; physical mapping is verified, the original import/regression/finding are preserved. These dispositions do not approve fabrication or operation. Both destinations remain private. Earlier issue descriptions below are historical and retain their original evidence scopes.

# Current blockers — 0.0.15-alpha.0

The electrical draft now contains 111 parts on nine A4 sheets. Native placement has zero reported errors/warnings; routing is disabled until the earlier gates pass.

## B011 — Selected USB footprint mismatch: resolved for C5143397

GCT USB4110-GF-A B4 (2024-05-22) agrees with all 16 native lands, physical signals and both Ø0.65 NPTH holes. See USB-MANUFACTURER-FOOTPRINT-AUDIT.json. Old C165948/C3020560 discrepancies remain historical and those components are unselected. The external exact-part STEP now passes nominal registration; full cable/mount clearance remains blocked under B017.

## B012 — Known imported-symbol drawing defect; electrical/PCB work may continue

C1974707 / ESDA25P35 ignores native schRotation=270: both zero-angle and rotated port vectors remain (0.8, 0) instead of the required (0, -0.8). An unchanged-import reproducer and failing regression are preserved. Core's React-symbol transform applies translation without rotation. C2965326/C94934/C1974707/C12067/C82045 also lack internal reference designator text; native board annotations identify them without editing definitions. The user accepted continuing electrical and PCB work because pin 1/cathode is VBUS, pin 2/anode is GND, and both physical pads match. ST recommends this TVS in the TCPP01 reference design (DS12900 §6.6.2); its pulse clamp is not a continuous-voltage limit or a regenerative brake. A released runtime fix is still needed for rotation; the failing regression and semantic CLI finding remain visible.

## B013/B006 — Startup, transient and braking qualification: BLOCKING stages 1/2

TPS26600 and unpowered SWD/ADC isolation are implemented. Current shunts are now 1 Ω, with a conservative peak-current screen about 0.34245 A rather than the obsolete 180 mΩ proposals. Remaining work: bootstrap current budget, capacitor effective values/ripple, thermal/pulse ratings, protection tolerances/transients, contract-aware fault behavior and regenerative energy. The VBUS ADC measures upstream of the eFuse, not regenerative VM. The user reconfirmed the exact store motor rather than an external load envelope. The motor SKU alone does not bound load inertia, maximum speed, deceleration or backdrive energy; those operating limits remain unqualified. Reverse blocking is not a brake.

## B016 — Rear encoder arrangement: closed for the default open-loop review assembly

The selected motor has no rear shaft. The brief permits an unpopulated encoder; the review BOM now explicitly omits U4/C6. Their footprints remain optional, with no qualified magnet location or feedback claim. Relocating or enabling an encoder would require a new mechanical review.

## B017 — PCB/motor attachment: BLOCKING stages 1/3

The exact manufacturer's STEP is valid and unchanged. No rear thread/engagement/preload qualification is supplied for the structural fasteners. The PCB now has four Ø2.5 mm controller/carrier holes and all-layer fastener keepouts. The proposed front-flange carrier has been generated and checked against the exact motor BRep and all 111 actual exported component mesh envelopes; no nominal collisions were found (minimum 1.00 mm component clearance). A front-flange wraparound carrier using the known 4×M3 front pattern, or an independently qualified body clamp, can avoid altering rear structural screws; the front-flange carrier is now a concrete prototype study, with production tolerances, strength and mating cable/harness qualification still pending. Connector bodies, mating harnesses and support clearances must be checked together. Exploded +65 mm motor separation is display-only.

## B019 — Selected USB CAD inventory/registration: resolved; full assembly remains blocked

C5143397's official footprint is unchanged. The board attaches a byte-exact USB4110-GF-A TraceParts AP242 STEP from the public mjbots/fdcanusb mirror. GCT and Ultra Librarian require sign-in for the offered downloads; no account or access gate was bypassed. SOURCE.json records the public source, Git blob and checksum. The model is not claimed to be a direct authenticated GCT download.

The B4 drawing envelope, both locating pegs and all 20 physical landings align with the generated supplier holes/lands. Native rotation/origin is checked against actual GLB vertices as well as the BRep. `test:assembly` now passes the 112-model inventory and `test:usb-model` passes nominal connector registration. This closes model absence and nominal registration only. Carrier/support, mating-cable envelope, tolerance stack and physical assembly remain unqualified under B017.

## B020 — New supervisor and motor-connector import findings: avoided through official alternatives

C53283913's pin-3 square loses its 45° rotation; it is excluded and replaced by audited C5218924. Motor connector C265102 has 1.80 mm hold-down lands versus JST 1.50 ±0.10; C265332 and C157926 alternatives also differ from their reference layouts. These are excluded. C189895 uses its own unaltered footprint and passes the catalogue's specified dimensions. Mating harness/model placement and stock freeze remain pending.

## B018 — Private source/CAD publication verified; hosted infrastructure failed

The user authorized creation. Private GitHub repository `AnasSarkiz/smart-nema14-motor-controller`, branch `main`, received commit 9eb6e1a. The private tscircuit package is `AnasSarkiz/smart-nema14-motor-controller--01a0fd9b`. The initial full-reference CLI upload encountered HTTP 413 and timeouts. The scoped revision-13 source/CAD distribution uploaded through the supported compressed archive API, and all 422 initial files passed exact SHA256 readback. Release 1b9388cf-42f9-40d2-8097-17158935154e is latest and ready to build; the later hosted job failed before code execution after eleven sandbox-capacity retries. The source/readback receipt remains valid; a new revision must be checked separately.

## B022 — Large reference PDF transport limitation

The revision-12 full-reference upload cannot transfer references/TPS25947.pdf and references/TPS2660.pdf through the registry's request-limited inline/archive API. The original PDFs remain in GitHub and were used for validation. Revision 13 uses an explicitly scoped source/CAD registry distribution with downloaded reference PDFs/ZIPs kept in the full GitHub repository. This is not a fabrication-check exception. Exact current CAD assets must all upload and match before the source release is declared complete.

## B021 — Public store visibility pending explicit approval

Automatic approval review rejected the public-visibility choice as public disclosure without explicit authorization. Both resources remain private; the user has been asked to approve making the concrete prototype destinations public. No public release is claimed.

## B007/B008 — Stackup and remaining qualification

JLC04161H-3313 and conservative manufacturer rules are selected in mechanical/manufacturing-rules.json. Native routing rules, actual copper and USB impedance construction still need verification. Review every footprint/model, critical power loop, silkscreen, test-point access, and final placement against the actual mounting design. These checks are incomplete even though the native placement algorithm reports no violations.

## B023 — eFuse output rating during disconnect: resolved by revision 15

TPS26600RHFR/C2155767 replaces TPS259470L using its own official footprint and exact manufacturer CAD. Its independently specified 60 V operating OUT / 62 V absolute rating removes the former VIN-relative rating concern. All 25 physical pads match supplier geometry and manufacturer package dimensions. This does not raise the board's 29 V driver limit. Selected current-limit, dV/dt, isolated RTN and switch mappings pass audit; startup/HF/thermal/firmware qualification remains under B013.

## Historical issue records — superseded where stated above

# Current revision 0.0.9-alpha.0 issues

User-selected STEPPERONLINE 14HM11-0404S replaces Phidgets 3323_0.
B003/B014/B015 below describe the superseded Phidgets assembly only.
B011/B012/B013 and incomplete electrical/BOM work remain active.

## B016 — Encoder decision and single-shaft feedback: BLOCKING scope/placement

The selected motor has no projecting rear shaft. The previous AS5600/magnet
assembly cannot be reused. Encoder feedback is optional for stepping; open-loop
first prototype is recommended. User asked whether it is needed, but has not
approved removing or relocating the optional electrical draft. Stop dependent
encoder placement until this is resolved.

## B017 — Rear PCB attachment: BLOCKING stages 1/3

Exact official STEP and drawing acquired and inspected. Drawing specifies front
4×M3 / 26 mm holes, not rear screw engagement or replacement lengths. The STEP
rear corner fasteners do not alone qualify four posts. Previous two-post holes
and hardware removed from the active reference. Manufacturer fastener details or
an independently qualified carrier are needed; no assembled fit approval.

## B018 — Publication destination: BLOCKING remote updates

Standing workspace instruction requires GitHub push and matching tscircuit
publication. Local board Git has no remote; destination repository and branch
unknown. Package identity exists, destination/access not verified. Neither remote
updated; no repository is invented. Local revision/checksums preserved.

## Historical issues and continuing electrical blockers

# Issues and remaining work

Revision 0.0.7-alpha.0, 2026-10-03 local time.

## B001 - STM32 critical label loss: RESOLVED tooling issue

Part C2847904 / STM32G0B1CBT6, stage 2. Older bundled importer output lost
labels on physical pins 6, 7, 33 and 34. Global tscircuit was updated to
0.0.2729, then the component was regenerated with released `easyeda@0.0.360`.
Current aliases are VDD/VDDA, VSS/VSSA, PA11_PA9_ and PA12_PA10_.
The unchanged critical-label audit passes. Old outputs are preserved.
No manual component edits, pin overrides or generic replacements were used.
This is no longer a component blocker; full application qualification remains stage 2 work.

## B002 - TCPP control/fault label loss: RESOLVED tooling issue

Part C1121848 / TCPP01-M12, stage 2. Regeneration with released
`easyeda@0.0.360` restores physical pin 10 DB and pin 11 FLT.
The unchanged audit passes. No component definition was manually patched.
The complete sink protection circuit remains to be designed and reviewed.

## B003 - Exact rear assembly: BLOCKING mechanical qualification

Motor identity and drawing acquisition are RESOLVED in revision 0.0.8:
Phidgets 3323_0 / 35STH40-1004B, original official drawing and STEP.
Native diagnostic assembly uses only its two rear M1.6 locations on the
14.5 mm / 40 degree circle; front M3 locations are excluded from PCB holes.

Stages 1/3 remain blocked: proposed hardware is not sourced/qualified,
2.2 mm PCB clearance holes permit translation larger than the AS5600
0.25 mm axis allowance without an alignment/registration process, and final
motor/IO connectors and mating cables are absent. Nominal centering is
exact in the native PCB frame; actual physical centering is not established.
B014/B015 additionally block the requested 3D assembly approval.

## B004 - Complete schematic and BOM: IN PROGRESS

Stages 2 and 3. Six A4 draft sheets with 56 imported parts implement MCU,
encoder, CAN, logic buck, TMC2209 support and a USB/CC frontend. Downstream protected power,
programmer power, temperature, LEDs, termination and external connectors
remain unfinished. A partial schematic is not a functioning controller.
Verify each supplier import, pin/function, rating, footprint, model and assembler
inventory before accepting the complete BOM. C2 effective capacitance at 3.3 V
must be qualified; nominal 4.7 uF alone does not establish this.

## B005 - Official programmer power integration: PENDING DESIGN

Stage 2. `StandardJstSwdResetSide` pin 1 is VOUT from the programmer's voltage
selector, not an established passive VTREF input. Complete 3.3 V operation,
power isolation/backfeed handling and documented series resistors before wiring.
The required official package is retained; no custom connector is substituted.

## B006 - Motor current, thermal and regeneration envelope: PENDING DESIGN

Stages 1 and 2. Resolve RMS/peak convention against the exact motor,
load/speed/inertia, PD current budget, fallback and braking energy.
1.2 A/phase is an intended upper target, not a measured rating.
The 180 mOhm / 1 W sense draft has nominal 1.149 A RMS full scale and a
proposed 1.0 A firmware cap; it cannot qualify the 1.2 A upper target.
Preliminary buck/sense/bulk-energy calculations are in references/POWER-AND-MOTOR-REVIEW.md.
Motor bulk stores only 12.9 mJ extra between 20 V and 23 V nominal: it cannot
replace a regenerative-energy solution. Complete power-path/fault calculations
against the exact motor/load, then physical tests.

## B007 - Stackup and copper geometry: PENDING LATER STAGES

Stages 1, 3, 4 and 6. Choose the manufacturer's four-layer stackup, thickness,
copper weight and impedance construction. Current previews contain no PCB
geometry, so they cannot qualify trace width, drills, vias or power bottlenecks.

## B008 - Datasheet/package visual review: PENDING REVIEW

Earlier local ST PDF downloads failed; those diagnostics remain in revision
0.0.1 evidence. Current manufacturer PDF text was accessed through the web;
a working AS5600 PDF URL is now recorded in references/SOURCES.md.
Full rendered land-pattern and 3D registration review remains pending.
No missing component label is attributed to these download failures.

## Draft warnings reviewed

AS5600 and TMC2209 lack a `requires_power` classification. These two
metadata warnings remain visible. The official MCU importer now supplies
manufacturer pin attributes, including VSS ground classification; its prior
warning is resolved without manual edits. Independent generated-net checks
confirm U1 pin 7 to GND, U4 pins 1/2 to 3.3 V and U2 pins 15 to V3V3,
22/28 to VM and 3/18/29 to GND. Accept the remaining metadata warnings only
for this schematic draft; full application/footprint/fabrication qualification
remains open.

## Remaining fabrication stages

No PCB placement, routed shorts/DRC, routed snapshots, Gerbers/drills/assembly
BOM/CPL, assembler feedback or physical tests have been completed.
There are no routes to save or manually repair yet.

## B009 - Candidate import audit: C5127775 RESOLVED; library failures excluded

Stage 2. Official `tsci upgrade` completed, global tscircuit 0.0.2732 resolves
CLI 0.1.2230; board dependencies pin that CLI and EasyEDA 0.0.366.
Converter #587/#588 and CLI #5111 merge status was independently verified.
C5127775 regenerates as a native 0.18 Ω resistor with original pins/pads 1/2.
The preserved legacy generic file is excluded, not patched.
R5/R6 now use this genuine 180 mOhm/1 W/1% import.

C2046441, C5127782 and C723743 remain supplier-library unavailable.
Verified replacements imported through the official CLI:

- C19947652 / Bourns SRN6028C-3R9M: 3.9 uH; L1 now uses its own exact
  footprint. Manufacturer dimensions and preliminary ripple calculation reviewed.
- C5127775 / Milliohm HoLRT1206-1W-180mR-1%: replaces unavailable C5127782.
- C5127776 / Milliohm HoLRT1206-1W-150mR-1%: native 0.15 Ω electrical
  candidate for C723743; not instantiated. AEC-Q200 qualification is unestablished.

Audit passes raw resistance, exact supplier identities and all 67 physical
pin-to-pad mappings across these three parts plus regenerated MCU/TCPP01.
An isolated unrouted footprint fixture has zero placement errors/warnings.
This is not full 35 x 35 mm board placement. Current assembler stock, worst-case
current, resistor pulse/temperature ratings and complete-board qualification
remain pending. See evidence/rev-0.0.4-alpha.0/IMPORT-PIN-PAD-AUDIT.json and
IMPORT-PROVENANCE.json. No generated component was manually edited.

## B010 - Protected USB power path: IN PROGRESS

TCPP CTRLVBUS pin 6 was incorrectly reserved for a GPIO in the candidate plan;
it is now correctly identified as an analog OVP divider input. No incorrect
connection was wired. VBUS_INRUSH_OUT and VM are unsupplied draft interfaces.
Resolve default-5 V bootstrap, <=10 uF connector-side capacitance, controlled
bulk charging, reverse-current protection, OVP tolerances and regeneration
before connecting these supplies or enabling PCB routing. Imported TI C3662793
eFuse is an unused candidate; application/footprint qualification is pending.

## Latest-runtime recheck — revision 0.0.5

Global/local tscircuit are 0.0.2733, core 0.0.2052, CLI 0.1.2230, converter
0.0.366. Original C2046441, C5127782 and C723743 were retried through the
latest official importer; all fail with missing-library data and exit 1.
Their supported replacement draft still builds. C79815 and C465949 were
regenerated without edits; the two requires_power metadata warnings persist.
Critical-label checks, 86 physical-pin net checks and expanded 104 raw-symbol/
physical-port/pad mappings pass. Isolated fixture placement has zero errors
or warnings. B003-B008/B010 design/requirement work remains unfinished as
listed above; these are not resolved by dependency updates. Full per-blocker
status and logs: evidence/rev-0.0.5-alpha.0/BLOCKER-RECHECK.md.

## Selected alternatives — 0.0.6

C19947652 is selected for L1; C5127775 is selected for both R5/R6. Their own
unaltered official footprints are used. Original C2046441/C5127782 imports are
excluded and no active circuit requires them. C5127776 is the verified
150 mOhm electrical alternative for excluded C723743, retained unpopulated;
the active sense pair remains 180 mOhm. No AEC-Q200 claim is made.
Selection and remaining qualifications are recorded in
[evidence/rev-0.0.6-alpha.0/SUBSTITUTIONS.md](evidence/rev-0.0.6-alpha.0/SUBSTITUTIONS.md).

## B011 - USB connector footprint: BLOCKING component issue

C165948, Stages 2 and 3: imported shell slots 0.80 x 1.60 / 0.80 x 1.40 mm
versus HRO drawing 0.60 x 1.40 / 0.60 x 1.10 mm. Imported SMT land length
1.30 mm versus drawing 1.00 mm. Fresh official converter 0.0.368 preserves
the discrepancy; no manual footprint correction is allowed or applied.
GCT alternative C3020560 also imports 0.70 mm slot widths versus its 0.60 mm
recommendation (+/-0.05 mm drawing tolerance); it is unselected. Supplier
qualification or an officially imported alternative with verified lands is needed.
Dependent connector placement/fabrication work stops here.

## B012 - USB imported custom symbols: BLOCKING visual qualification

C2965326, C94934 and C1974707 lack internal reference text. Native board
annotations identify them in the draft without modifying imported symbols.
C1974707 still ignores chip schRotation=270 in rendered port geometry and
schematic-placement reports a remaining vertical-orientation issue. Pin/pad
links are correct; full Stage 2 visual qualification is blocked by these
import/runtime limitations. No warnings or checks are suppressed.

## B013 - USB power protection/startup: BLOCKING circuit qualification

U3 C1121848 threshold screen is 21.158-23.868 V with only 0.132 V margin to
its 24 V absolute limit at the high corner. This screen assumes unverified
R14 temperature behavior and omits dynamic overshoot/loading/leakage/aging.
The input TVS cannot guarantee a 24 V clamp. Unpowered VBUS ADC injection,
inrush/current/reverse protection, contract-aware shutdown and motor regen
are unresolved. Protected input stays disconnected from buck and motor.
See references/USB-PD-REVIEW.md and the recorded calculation JSON.

## Latest-runtime warning review - revision 0.0.7

Pin specification reports 11 warnings: Q_PD/D_VBUS underspecified; U4/U2,
J_USB/Q_PD/D_USB/D_VBUS lack requires_power; J_USB/Q_PD/D_VBUS lack
requires_ground. External high-side MOSFET and passive shunt ESD devices
need no separate VCC pin, and the MOSFET has no ground pin. Actual connector
VBUS/GND, ESD ground, TVS polarity and IC supplies are checked independently
by physical pin. Accept these metadata warnings only for draft connectivity,
not component or fabrication qualification. Missing symbol reference warnings
and D_VBUS orientation are recorded as B012, not silently accepted.
Original C2046441/C5127782/C723743 library failures still reproduce with
CLI 0.1.2232 / converter 0.0.368. The selected 3.9 uH/180 mOhm alternatives
remain valid imports; the 150 mOhm option stays unpopulated.

## B014 - Official Phidgets STEP / drawing shaft discrepancy: BLOCKING

Stages 1/3. Phidgets 3323_0 original STEP model is a valid BRep but its rear
shaft radius is 2.0 mm (4.0 mm diameter). Drawing 0DZ.252.001 and user lock
require 3.9 mm, tolerance +0/-0.15 mm. Rear projection and hole centers agree
with nominal drawing geometry; body 34.95 mm is below its 35.2 mm maximum.
Do not modify the model or substitute generic NEMA geometry. Manufacturer
clarification/corrected exact STEP or actual measured motor evidence is
required to resolve the discrepancy. Original files and measurements are
in references/motor/ and revision 0.0.8/OFFICIAL-MOTOR-STEP-CHECK.json.

## B015 - USB STEP / PCB registration: BLOCKING 3D qualification

Stages 2/3. Exact diagnostic CAD reports 0.358309 mm3 intersection between
unchanged C165948 STEP geometry and PCB after actual native imported
placement and drilled slots. Determine whether model origin, native CAD
placement or land geometry causes the mismatch before approving assembly.
This mechanical finding is not a new manufacturer footprint audit; that
audit remains gated until mechanics pass. B011 remains independently valid.
Never compensate by manually patching imported footprint/CAD metadata.

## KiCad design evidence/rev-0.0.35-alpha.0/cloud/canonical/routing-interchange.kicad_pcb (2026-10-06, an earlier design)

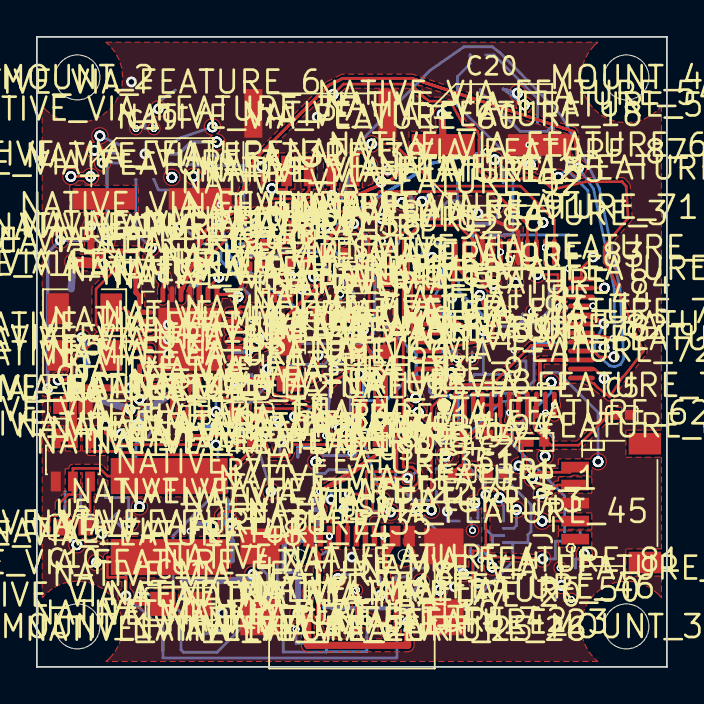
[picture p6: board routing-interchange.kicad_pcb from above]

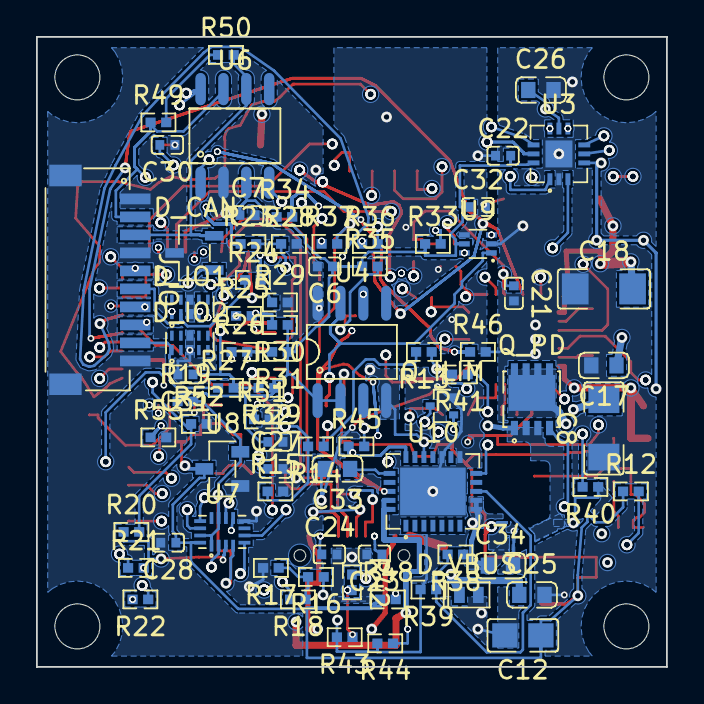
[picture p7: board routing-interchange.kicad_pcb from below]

Board: 4 copper layers, 35.0 x 35.0 mm, 213 parts (75 on the bottom side), 82 nets.

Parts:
C1: 100nF; C1
C2: 4.7uF; C2
C3: 100nF; C3
C4: 100nF; C4
C5: 100nF; C5
C6: 100nF; C6
C7: 100nF; C7
C8: 10uF; C8
C9: 100nF; C9
C10: 100nF; C10
C11: 22uF; C11
C12: 22uF; C12
C13: 22nF; C13
C14: 100nF; C14
C15: 4.7uF; C15
C16: 100nF; C16
C17: 100nF; C17
C18: 10uF; C18
C19: 100uF; C19
C20: 100uF; C20
C21: 100nF; C21
C22: 100nF; C22
C23: 330pF; C23
C24: 330pF; C24
C25: 2.2uF; C25
C26: 100nF; C26
C27: 100nF; C27
C28: 100nF; C28
C29: 100nF; C29
C30: 100nF; C30
C31: 100nF; C31
C32: 100nF; C32
C33: 2.2uF; C33
C34: 2.2uF; C34
D_CAN: SM712.TCT; D_CAN
D_IO1: TPD4E05U06DQAR; D_IO1
D_IO2: TPD4E05U06DQAR; D_IO2
D_USB: TPD2EUSB30ADRTR; D_USB
D_VBUS: ESDA25P35-1U1M; D_VBUS
J_IO: SM10B-SRSS-TB(LF)(SN); J_IO
J_MOTOR: SM04B-GHS-TB(LF)(SN); J_MOTOR
J_SWD: J_SWD
J_USB: USB4110-GF-A; J_USB
L1: 3.9µH; L1
LED_FAULT: XL-1608SYGC-06; LED_FAULT
LED_POWER: XL-1608SYGC-06; LED_POWER
LED_STATUS: XL-1608SYGC-06; LED_STATUS
MOUNT_1, MOUNT_2, MOUNT_3, MOUNT_4: hole_circle_holeDiameter2.5mm
NATIVE_VIA_FEATURE_1: NATIVE_VIA_FEATURE_1
NATIVE_VIA_FEATURE_2: NATIVE_VIA_FEATURE_2
NATIVE_VIA_FEATURE_3: NATIVE_VIA_FEATURE_3
NATIVE_VIA_FEATURE_4: NATIVE_VIA_FEATURE_4
NATIVE_VIA_FEATURE_5: NATIVE_VIA_FEATURE_5
NATIVE_VIA_FEATURE_6: NATIVE_VIA_FEATURE_6
NATIVE_VIA_FEATURE_7: NATIVE_VIA_FEATURE_7
NATIVE_VIA_FEATURE_8: NATIVE_VIA_FEATURE_8
NATIVE_VIA_FEATURE_9: NATIVE_VIA_FEATURE_9
NATIVE_VIA_FEATURE_10: NATIVE_VIA_FEATURE_10
NATIVE_VIA_FEATURE_11: NATIVE_VIA_FEATURE_11
NATIVE_VIA_FEATURE_12: NATIVE_VIA_FEATURE_12
NATIVE_VIA_FEATURE_13: NATIVE_VIA_FEATURE_13
NATIVE_VIA_FEATURE_14: NATIVE_VIA_FEATURE_14
NATIVE_VIA_FEATURE_15: NATIVE_VIA_FEATURE_15
NATIVE_VIA_FEATURE_16: NATIVE_VIA_FEATURE_16
NATIVE_VIA_FEATURE_17: NATIVE_VIA_FEATURE_17
NATIVE_VIA_FEATURE_18: NATIVE_VIA_FEATURE_18
NATIVE_VIA_FEATURE_19: NATIVE_VIA_FEATURE_19
NATIVE_VIA_FEATURE_20: NATIVE_VIA_FEATURE_20
NATIVE_VIA_FEATURE_21: NATIVE_VIA_FEATURE_21
NATIVE_VIA_FEATURE_22: NATIVE_VIA_FEATURE_22
NATIVE_VIA_FEATURE_23: NATIVE_VIA_FEATURE_23
NATIVE_VIA_FEATURE_24: NATIVE_VIA_FEATURE_24
NATIVE_VIA_FEATURE_25: NATIVE_VIA_FEATURE_25
NATIVE_VIA_FEATURE_26: NATIVE_VIA_FEATURE_26
NATIVE_VIA_FEATURE_27: NATIVE_VIA_FEATURE_27
NATIVE_VIA_FEATURE_28: NATIVE_VIA_FEATURE_28
NATIVE_VIA_FEATURE_29: NATIVE_VIA_FEATURE_29
NATIVE_VIA_FEATURE_30: NATIVE_VIA_FEATURE_30
NATIVE_VIA_FEATURE_31: NATIVE_VIA_FEATURE_31
NATIVE_VIA_FEATURE_32: NATIVE_VIA_FEATURE_32
NATIVE_VIA_FEATURE_33: NATIVE_VIA_FEATURE_33
NATIVE_VIA_FEATURE_34: NATIVE_VIA_FEATURE_34
NATIVE_VIA_FEATURE_35: NATIVE_VIA_FEATURE_35
NATIVE_VIA_FEATURE_36: NATIVE_VIA_FEATURE_36
NATIVE_VIA_FEATURE_37: NATIVE_VIA_FEATURE_37
NATIVE_VIA_FEATURE_38: NATIVE_VIA_FEATURE_38
NATIVE_VIA_FEATURE_39: NATIVE_VIA_FEATURE_39
NATIVE_VIA_FEATURE_40: NATIVE_VIA_FEATURE_40
NATIVE_VIA_FEATURE_41: NATIVE_VIA_FEATURE_41
NATIVE_VIA_FEATURE_42: NATIVE_VIA_FEATURE_42
NATIVE_VIA_FEATURE_43: NATIVE_VIA_FEATURE_43
NATIVE_VIA_FEATURE_44: NATIVE_VIA_FEATURE_44
NATIVE_VIA_FEATURE_45: NATIVE_VIA_FEATURE_45
NATIVE_VIA_FEATURE_46: NATIVE_VIA_FEATURE_46
NATIVE_VIA_FEATURE_47: NATIVE_VIA_FEATURE_47
NATIVE_VIA_FEATURE_48: NATIVE_VIA_FEATURE_48
NATIVE_VIA_FEATURE_49: NATIVE_VIA_FEATURE_49
NATIVE_VIA_FEATURE_50: NATIVE_VIA_FEATURE_50
NATIVE_VIA_FEATURE_51: NATIVE_VIA_FEATURE_51
NATIVE_VIA_FEATURE_52: NATIVE_VIA_FEATURE_52
NATIVE_VIA_FEATURE_53: NATIVE_VIA_FEATURE_53
NATIVE_VIA_FEATURE_54: NATIVE_VIA_FEATURE_54
NATIVE_VIA_FEATURE_55: NATIVE_VIA_FEATURE_55
NATIVE_VIA_FEATURE_56: NATIVE_VIA_FEATURE_56
NATIVE_VIA_FEATURE_57: NATIVE_VIA_FEATURE_57
NATIVE_VIA_FEATURE_58: NATIVE_VIA_FEATURE_58
NATIVE_VIA_FEATURE_59: NATIVE_VIA_FEATURE_59
NATIVE_VIA_FEATURE_60: NATIVE_VIA_FEATURE_60
NATIVE_VIA_FEATURE_61: NATIVE_VIA_FEATURE_61
NATIVE_VIA_FEATURE_62: NATIVE_VIA_FEATURE_62
NATIVE_VIA_FEATURE_63: NATIVE_VIA_FEATURE_63
NATIVE_VIA_FEATURE_64: NATIVE_VIA_FEATURE_64
NATIVE_VIA_FEATURE_65: NATIVE_VIA_FEATURE_65
NATIVE_VIA_FEATURE_66: NATIVE_VIA_FEATURE_66
NATIVE_VIA_FEATURE_67: NATIVE_VIA_FEATURE_67
NATIVE_VIA_FEATURE_68: NATIVE_VIA_FEATURE_68
NATIVE_VIA_FEATURE_69: NATIVE_VIA_FEATURE_69
NATIVE_VIA_FEATURE_70: NATIVE_VIA_FEATURE_70
NATIVE_VIA_FEATURE_71: NATIVE_VIA_FEATURE_71
NATIVE_VIA_FEATURE_72: NATIVE_VIA_FEATURE_72
NATIVE_VIA_FEATURE_73: NATIVE_VIA_FEATURE_73
NATIVE_VIA_FEATURE_74: NATIVE_VIA_FEATURE_74
NATIVE_VIA_FEATURE_75: NATIVE_VIA_FEATURE_75
NATIVE_VIA_FEATURE_76: NATIVE_VIA_FEATURE_76
NATIVE_VIA_FEATURE_77: NATIVE_VIA_FEATURE_77
NATIVE_VIA_FEATURE_78: NATIVE_VIA_FEATURE_78
NATIVE_VIA_FEATURE_79: NATIVE_VIA_FEATURE_79
NATIVE_VIA_FEATURE_80: NATIVE_VIA_FEATURE_80
NATIVE_VIA_FEATURE_81: NATIVE_VIA_FEATURE_81
NATIVE_VIA_FEATURE_82: NATIVE_VIA_FEATURE_82
NATIVE_VIA_FEATURE_83: NATIVE_VIA_FEATURE_83
NATIVE_VIA_FEATURE_84: NATIVE_VIA_FEATURE_84
NATIVE_VIA_FEATURE_85: NATIVE_VIA_FEATURE_85
NATIVE_VIA_FEATURE_86: NATIVE_VIA_FEATURE_86
NATIVE_VIA_FEATURE_87: NATIVE_VIA_FEATURE_87
NATIVE_VIA_FEATURE_88: NATIVE_VIA_FEATURE_88
NATIVE_VIA_FEATURE_89: NATIVE_VIA_FEATURE_89
NATIVE_VIA_FEATURE_90: NATIVE_VIA_FEATURE_90
NATIVE_VIA_FEATURE_91: NATIVE_VIA_FEATURE_91
NATIVE_VIA_FEATURE_92: NATIVE_VIA_FEATURE_92
NATIVE_VIA_FEATURE_93: NATIVE_VIA_FEATURE_93
NATIVE_VIA_FEATURE_94: NATIVE_VIA_FEATURE_94
NATIVE_VIA_FEATURE_95: NATIVE_VIA_FEATURE_95
NATIVE_VIA_FEATURE_96: NATIVE_VIA_FEATURE_96
NATIVE_VIA_FEATURE_97: NATIVE_VIA_FEATURE_97
NATIVE_VIA_FEATURE_98: NATIVE_VIA_FEATURE_98
Q_ILIM: DMG1012T-7; Q_ILIM
Q_PD: STL11N3LLH6; Q_PD
R1: 10kΩ; R1
R2: 4.7kΩ; R2
R3: 4.7kΩ; R3
R4: 1kΩ; R4
R5: 1Ω; R5
R6: 1Ω; R6
R7: 10kΩ; R7
R8: 10kΩ; R8
R9: 10kΩ; R9
R10: 10kΩ; R10
R11: 10kΩ; R11
R12: 10kΩ; R12
R13: 100kΩ; R13
R14: 1kΩ; R14
R15: 6.04kΩ; R15
R16: 220kΩ; R16
R17: 10kΩ; R17
R18: 1kΩ; R18
R19: 10kΩ; R19
R20: 1kΩ; R20
R21: 1kΩ; R21
R22: 1kΩ; R22
R23: 1kΩ; R23
R24: 1kΩ; R24
R25: 1kΩ; R25
R26: 1kΩ; R26
R27: 1kΩ; R27
R28: 10kΩ; R28
R29: 10kΩ; R29
R30: 10kΩ; R30
R31: 10kΩ; R31
R32: 10kΩ; R32
R33: 10kΩ; R33
R34: 10kΩ; R34
R35: 1kΩ; R35
R36: 1kΩ; R36
R37: 1kΩ; R37
R38: 100kΩ; R38
R39: 47kΩ; R39
R40: 100kΩ; R40
R41: 1kΩ; R41
R42: 4.7kΩ; R42
R43: 6.04kΩ; R43
R44: 24kΩ; R44
R45: 24kΩ; R45
R46: 10kΩ; R46
R48: 10kΩ; R48
R49: 120Ω; R49
R50: 0Ω; R50
R51: 100kΩ; R51
R52: 100kΩ; R52
R53: 100kΩ; R53
U1: STM32G0B1CBT6; U1
U2: TMC2209-LA; U2
U3: TCPP01-M12; U3
U4: AS5600-ASOM; U4
U5: AP63203WU-7; U5
U6: SN65HVD230DR; U6
U7: TMUX1511RSVR; U7
U8: TLV803EA30DBZR; U8
U9: TMP112AIDRLR; U9
U10: TPS26600RHFR; U10

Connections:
BUCK_BST: C10.1, U5.6
BUCK_SW: C10.2, L1.1, U5.5
CAN_H: D_CAN.1, J_IO.2, R49.1, U6.7
CAN_L: D_CAN.2, J_IO.3, R50.2, U6.6
CAN_RS: R34.2, U1.42, U6.8
CAN_RX: U1.44, U6.4
CAN_TERM_LINK: R49.2, R50.1
CAN_TX: U1.45, U6.1
EFUSE_DVDT: C33.1, U10.20
EFUSE_EN: R38.2, R39.1, U10.10
EFUSE_FLT_N: R48.2, U1.43, U10.22
EFUSE_ILIM: R44.1, R45.1, U10.19
EFUSE_ILIM_SWITCH: Q_ILIM.3, R45.2
EFUSE_OVP: R42.2, R43.1, U10.12
EFUSE_OVP_TOP_1: R40.2, R41.1
EFUSE_OVP_TOP_2: R41.2, R42.1
EFUSE_RTN: C33.2, Q_ILIM.2, R39.2, R43.2, R44.2, U10.13, U10.15, U10.25
EXT_DIR: R24.2, R29.1, U1.20
EXT_DIR_CONN: D_IO1.2, J_IO.6, R24.1
EXT_ENABLE_N: R25.2, R30.2, U1.21
EXT_ENABLE_N_CONN: D_IO1.4, J_IO.7, R25.1
EXT_STEP: R23.2, R28.1, U1.19
EXT_STEP_CONN: D_IO1.1, J_IO.5, R23.1
GND: C1.2, C2.2, C3.2, C4.2, C5.2, C6.2, C7.2, C8.2, C9.2, C11.2, C12.2, C15.2, C16.2, C17.2, C18.2, C19.2, C20.2, C21.2, C22.2, C23.2, C24.2, C25.2, C26.2, C27.2, C28.2, C29.2, C30.2, C31.2, C32.2, C34.2, D_CAN.3, D_IO1.3, D_IO1.8, D_IO2.3, D_IO2.8, D_USB.3, D_VBUS.2, J_IO.1, J_IO.4, J_IO.10, J_IO.11, J_IO.12, J_MOTOR.5, J_MOTOR.6, J_SWD.3, J_USB.8, J_USB.9, J_USB.10, J_USB.11, J_USB.22, J_USB.23, LED_FAULT.1, LED_POWER.1, LED_STATUS.1, R5.2, R6.2, R8.2, R9.2, R11.2, R15.2, R17.2, R28.2, R29.2, R46.2, R51.2, R52.2, R53.2, U1.7, U1.29, U1.32, U2.3, U2.7, U2.9, U2.10, U2.13, U2.18, U2.20, U2.25, U2.29, U3.2, U3.13, U4.4, U4.8, U5.4, U6.2, U7.8, U8.1, U9.2, U9.4, U10.17
I2C_SCL: R2.2, U1.47, U4.7, U9.1
I2C_SDA: R3.2, U1.48, U4.6, U9.6
LED_FAULT_A: LED_FAULT.2, R37.2
LED_FAULT_DRIVE: R37.1, U1.31
LED_POWER_A: LED_POWER.2, R35.2
LED_STATUS_A: LED_STATUS.2, R36.2
LED_STATUS_DRIVE: R36.1, U1.30
LIMIT1: C30.1, R26.2, R31.2, U1.22
LIMIT1_CONN: D_IO1.5, J_IO.8, R26.1
LIMIT2: C31.1, R27.2, R32.2, U1.23
LIMIT2_CONN: D_IO2.1, J_IO.9, R27.1
MOTOR_A1: J_MOTOR.1, U2.24
MOTOR_A2: J_MOTOR.2, U2.21
MOTOR_B1: J_MOTOR.3, U2.26
MOTOR_B2: J_MOTOR.4, U2.1
NRST: C5.1, R1.2, R22.2, U1.10
NRST_CONN: J_SWD.5, U7.10
NRST_GUARDED: R22.1, U7.9
PD_CC1_CONN: C23.1, J_USB.18, U3.7
PD_CC1_MCU: U1.28, U3.3
PD_CC2_CONN: C24.1, J_USB.15, U3.9
PD_CC2_MCU: U1.27, U3.1
PD_DB: U1.24, U3.10
PD_FLT: R12.2, U1.25, U3.11
PD_GATE: Q_PD.4, U3.5
PD_OVP: R14.2, R15.1, U3.6
PD_OVP_SERIES: R13.2, R14.1
POWER_GOOD: R19.2, U7.1, U7.4, U7.11, U7.15, U8.2
POWER_HIGH_CURRENT: Q_ILIM.1, R46.1, U1.26
SWCLK: R21.2, R53.1, U1.36
SWCLK_CONN: J_SWD.4, U7.5
SWCLK_GUARDED: R21.1, U7.6
SWDIO: R20.2, R52.1, U1.35
SWDIO_CONN: J_SWD.2, U7.2
SWDIO_GUARDED: R20.1, U7.3
TEMP_ALERT_N: R33.2, U1.12, U9.3
TMC_5VOUT: C15.1, R10.1, U2.8
TMC_CPI: C13.2, U2.5
TMC_CPO: C13.1, U2.4
TMC_DIAG: U1.16, U2.11
TMC_DIR: R9.1, U1.18, U2.19
TMC_ENABLE_N: R7.2, U1.15, U2.2
TMC_SENSE_A: R5.1, U2.23
TMC_SENSE_B: R6.1, U2.27
TMC_STEP: R8.1, U1.17, U2.16
TMC_UART_RX: R4.2, U1.14, U2.14
TMC_UART_TX: R4.1, U1.13
TMC_VCP: C14.1, U2.6
TMC_VREF: C21.1, R10.2, R11.1, U2.17
USB_DM: D_USB.2, J_USB.12, J_USB.17, U1.33
USB_DP: D_USB.1, J_USB.13, J_USB.16, U1.34
V3V3: C1.1, C2.1, C3.1, C4.1, C6.1, C7.1, C11.1, C12.1, C16.1, C22.1, C28.1, C29.1, C32.1, L1.2, R1.1, R2.1, R3.1, R7.1, R12.1, R19.1, R30.1, R31.1, R32.1, R33.1, R34.1, R35.1, R48.1, U1.4, U1.5, U1.6, U2.15, U3.12, U4.1, U4.2, U5.1, U6.3, U7.16, U8.3, U9.5
VBUS_ADC: C27.1, R51.1, U1.11, U7.13
VBUS_ADC_PRE_GUARD: R18.2, U7.14
VBUS_CONN: C25.1, C26.1, D_VBUS.1, J_USB.20, J_USB.21, Q_PD.5, Q_PD.6, Q_PD.7, Q_PD.8, Q_PD.9, R13.1, U3.8
VBUS_DIV: R16.2, R17.1, R18.1
VBUS_PROTECTED: C34.1, Q_PD.1, Q_PD.2, Q_PD.3, R16.1, R38.1, R40.1, U3.4, U10.8, U10.9
VM: C8.1, C9.1, C14.2, C17.1, C18.1, C19.1, C20.1, U2.22, U2.28, U5.2, U5.3, U10.23, U10.24

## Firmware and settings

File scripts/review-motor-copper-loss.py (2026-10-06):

"""Bound motor track/barrel DC losses without claiming thermal qualification.

Reads native geometry and the existing width/current audit. Parallel copper is
ignored; each distinct used via is charged a full board-thickness barrel. Copper
thickness, plating and temperature remain explicit engineering assumptions.
"""
import hashlib
import json
import math
import sys
from pathlib import Path


def sha256(path):
    return hashlib.sha256(path.read_bytes()).hexdigest()


def review_motor_path(net, context):
    segments = context['width_records'][net]['segments']
    traces = context['motor_traces'][net]
    assert len(traces) == 1, f'{net}: review branched routing before applying a series bound'
    trace = traces[0]
    terminals = {point[key] for point in trace['route']
                 for key in ('start_pcb_port_id', 'end_pcb_port_id') if key in point}
    assert len(terminals) == 2, f'{net}: expected driver-to-connector pair'
    owners = sorted(context['pcb_port_owners'][terminal] for terminal in terminals)
    assert owners == sorted(context['expected_owners'][net]), (net, owners)
    segment_resistances = []
    required_thicknesses = []
    for segment in segments:
        layer = segment['layer']
        thickness = context['stackup']['inner_copper_mm' if layer in ('inner1', 'inner2') else 'outer_copper_mm']
        finished_width = segment['width_mm'] * context['width_fraction']
        resistance = context['rho_ohm_mm'] * segment['length_mm'] / (finished_width * thickness)
        coefficient = .024 if layer in ('inner1', 'inner2') else .048
        required_area_mil2 = (context['peak_a'] / (coefficient * 30**.44))**(1/.725)
        required_thickness = required_area_mil2 * .0254**2 / finished_width
        segment_resistances.append(resistance)
        required_thicknesses.append({'layer': layer, 'trace_id': segment['trace_id'],
                                    'segment_index': segment['segment_index'],
                                    'nominal_width_mm': segment['width_mm'],
                                    'minimum_thickness_under_existing_30c_screen_mm': required_thickness})
    vias_by_position = {}
    for point in trace['route']:
        if point['route_type'] != 'via':
            continue
        position = (round(point['x'], 6), round(point['y'], 6))
        hits = [via for via in context['vias']
                if math.hypot(via['x']-point['x'], via['y']-point['y']) < .00001]
        assert len(hits) == 1, (net, position, len(hits))
        vias_by_position[position] = hits[0]
    barrel_resistances = []
    for via in vias_by_position.values():
        plating = context['plating_mm']
        # Finished-hole circumference plus wall thickness, assuming uniform wall.
        area_mm2 = math.pi * ((via['hole_diameter']/2+plating)**2 - (via['hole_diameter']/2)**2)
        barrel_resistances.append(context['rho_ohm_mm'] * context['board_max_mm'] / area_mm2)
    track_r = sum(segment_resistances)
    barrel_r = sum(barrel_resistances)
    return {'net': net, 'physical_terminals': owners, 'nonzero_segments': len(segments),
            'track_length_mm': sum(segment['length_mm'] for segment in segments),
            'distinct_used_through_vias': len(vias_by_position),
            'trace_series_resistance_bound_ohms': track_r,
            'barrel_series_resistance_bound_ohms': barrel_r,
            'total_series_resistance_bound_ohms': track_r+barrel_r,
            'voltage_drop_at_phase_peak_v': context['peak_a']*(track_r+barrel_r),
            'dc_loss_at_phase_peak_w': context['peak_a']**2*(track_r+barrel_r),
            'maximum_single_barrel_loss_w': context['peak_a']**2*max(barrel_resistances, default=0),
            'required_thickness_by_layer_mm': {
                layer: max(row['minimum_thickness_under_existing_30c_screen_mm']
                           for row in required_thicknesses if row['layer'] == layer)
                for layer in sorted({row['layer'] for row in required_thicknesses})},
            'segment_thickness_requirements': required_thicknesses}


def main():
    circuit_path, width_path, power_path, report_path = map(Path, sys.argv[1:5])
    circuit = json.loads(circuit_path.read_text())
    width = json.loads(width_path.read_text())
    power = json.loads(power_path.read_text())
    rules_path = Path('mechanical/manufacturing-rules.json')
    motor_path = Path('mechanical/design-constraints.json')
    rules = json.loads(rules_path.read_text())
    motor = json.loads(motor_path.read_text())
    digest = sha256(circuit_path)
    assert digest == width['canonical_sha256']
    assert width['ordinary_width_and_phase_segment_screens_passed']
    peak = power['intended_prototype_envelope']['phase_peak_screen_a']
    assert peak == width['phase_peak_screen_a']
    sources = {row['source_component_id']: row['name'] for row in circuit if row['type'] == 'source_component'}
    ports = {row['source_port_id']: (sources[row['source_component_id']], row['pin_number'])
             for row in circuit if row['type'] == 'source_port' and row.get('pin_number') is not None}
    source_traces = {row['source_trace_id']: row for row in circuit if row['type'] == 'source_trace'}
    nets = {row['source_net_id']: row['name'] for row in circuit if row['type'] == 'source_net'}
    motor_names = ('MOTOR_A1', 'MOTOR_A2', 'MOTOR_B1', 'MOTOR_B2')
    motor_traces = {name: [] for name in motor_names}
    for row in circuit:
        if row['type'] != 'pcb_trace':
            continue
        names = [nets[net] for net in source_traces[row['source_trace_id']]['connected_source_net_ids']]
        for name in motor_names:
            if name in names:
                motor_traces[name].append(row)
    assert all(set(via['layers']) == {'top', 'inner1', 'inner2', 'bottom'}
               for via in circuit if via['type'] == 'pcb_via')
    context = {'width_records': {row['net']: row for row in width['nets']},
               'motor_traces': motor_traces, 'source_traces': source_traces,
               'pcb_port_owners': {row['pcb_port_id']: ports[row['source_port_id']]
                                   for row in circuit if row['type'] == 'pcb_port'
                                   and row['source_port_id'] in ports},
               'vias': [row for row in circuit if row['type'] == 'pcb_via'],
               'expected_owners': {'MOTOR_A1': [('U2', 24), ('J_MOTOR', 1)],
                                   'MOTOR_A2': [('U2', 21), ('J_MOTOR', 2)],
                                   'MOTOR_B1': [('U2', 26), ('J_MOTOR', 3)],
                                   'MOTOR_B2': [('U2', 1), ('J_MOTOR', 4)]},
               'stackup': rules['stackup'], 'width_fraction': .8, 'peak_a': peak,
               'rho_ohm_mm': 1.724e-5*(1+.00393*(80-20)),
               'plating_mm': .018,
               'board_max_mm': rules['stackup']['finished_thickness_mm']*1.1}
    results = [review_motor_path(name, context) for name in motor_names]
    by_name = {row['net']: row for row in results}
    loops = []
    for phase in ('A', 'B'):
        resistance = sum(by_name[f'MOTOR_{phase}{leg}']['total_series_resistance_bound_ohms'] for leg in (1, 2))
        loops.append({'phase': phase, 'two_lead_series_resistance_bound_ohms': resistance,
                      'fraction_of_25ohm_nominal_winding_resistance': resistance/motor['phase_resistance_ohms'],
                      'two_lead_drop_at_peak_v': peak*resistance,
                      'two_lead_dc_loss_at_peak_w': peak**2*resistance})
    report = {'canonical_sha256': digest, 'input_hashes': {
                str(path): sha256(path) for path in (circuit_path, width_path, power_path, rules_path, motor_path)},
              'scope': __doc__, 'assumptions': {
                'uniform_copper_temperature_c': 80, 'resistivity_20c_ohm_mm': 1.724e-5,
                'temperature_coefficient_per_c': .00393, 'finished_width_fraction': .8,
                'outer_copper_mm': rules['stackup']['outer_copper_mm'],
                'inner_copper_mm': rules['stackup']['inner_copper_mm'],
                'uniform_barrel_plating_mm': context['plating_mm'],
                'charged_length_per_distinct_via_mm': context['board_max_mm'],
                'copper_and_plating_are_guaranteed_minima': False,
                'parallel_tracks_pads_pours_ignored': True,
                'conservative_simultaneous_phase_peak_current_a': peak},
              'paths': results, 'phase_loops': loops,
              'both_phase_loops_simultaneous_peak_dc_loss_bound_w': sum(row['two_lead_dc_loss_at_peak_w'] for row in loops),
              'method': 'rho(T)*L/A per emitted nonzero segment at -20% width; one full-thickness barrel per distinct used hole. Required track thickness inverts the existing IPC-2221 30 C screen.',
              'unqualified': ['Guaranteed minimum manufactured copper/plating and process acceptance',
                              'Loaded VM/VBUS/V3V3 and ground pour-neck/current-sharing network',
                              'IPC-2152/thermal simulation or temperature measurements',
                              'Switching-loop inductance, driver/eFuse/buck junction temperatures and transients',
                              'Physical motor operation and firmware current limits'],
              'prototype_fabrication_ready': False}
    report_path.write_text(json.dumps(report, indent=2)+'\n')
    print(json.dumps({'motor_paths_reviewed': len(results), 'phase_loops': loops,
                      'total_copper_peak_loss_bound_w': report['both_phase_loops_simultaneous_peak_dc_loss_bound_w']}))


if __name__ == '__main__':
    main()

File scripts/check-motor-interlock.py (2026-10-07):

"""Independent source-pin truth and manufacturer electrical-corner review.

Datasheet limits are recorded with their actual temperature/voltage scope.
This check does not simulate silicon or invent physical startup measurements.
"""
import hashlib
import itertools
import json
from pathlib import Path
import sys

circuit_path, report_path = map(Path, sys.argv[1:3])
circuit_bytes = circuit_path.read_bytes()
circuit = json.loads(circuit_bytes)
components = {row['name']: row for row in circuit if row['type'] == 'source_component'}
nets = {row['source_net_id']: row['name'] for row in circuit if row['type'] == 'source_net'}
ports = [row for row in circuit if row['type'] == 'source_port']
traces = [row for row in circuit if row['type'] == 'source_trace']


def pin_net(reference, number):
    owner = components[reference]['source_component_id']
    port = next(row for row in ports if row['source_component_id'] == owner and row['pin_number'] == number)
    names = {nets[net] for trace in traces if port['source_port_id'] in trace['connected_source_port_ids'] for net in trace['connected_source_net_ids']}
    assert len(names) == 1, (reference, number, names)
    return names.pop()


assert pin_net('U2', 15) == pin_net('R7', 1) == pin_net('U_MOTOR_ENN', 5) == 'V3V3'
assert pin_net('U2', 2) == pin_net('R7', 2) == pin_net('U_MOTOR_ENN', 4) == 'TMC_ENABLE_N'
assert components['U_MOTOR_ENN']['supplier_part_numbers']['jlcpcb'] == ['C485081']
for pin, expected in {1: 'GND', 2: 'GND', 3: 'MOTOR_ENABLE_DRIVE', 6: 'MOTOR_POWER_GOOD'}.items():
    assert pin_net('U_MOTOR_ENN', pin) == expected
assert pin_net('U_MOTOR_SUPERVISOR', 2) == 'MOTOR_POWER_GOOD'
assert pin_net('D_PD_VALID', 1) == 'PD_LOAD_ENABLE_N'  # purchased cathode
assert pin_net('D_PD_VALID', 2) == 'PD_PATH_INVALID_N'  # purchased anode
assert components['D_PD_VALID']['supplier_part_numbers']['jlcpcb'] == ['C668868']
assert not {'Q_MOTOR_ENABLE', 'Q_MOTOR_POWER_GOOD', 'R_MOTOR_GATE_SERIES', 'R_MOTOR_GATE_OFF'} & components.keys()
assert components['R7']['resistance'] == 10000
assert components['R_MOTOR_BOOT_PULLUP']['resistance'] == 180000

# Independent TI SCES417L eight-row multiplexer-inverting truth table, not
# inferred from this design's intended NAND name. IN1 is physically tied low.
gate98_table = {(0, 0, 0): 1, (0, 0, 1): 1, (0, 1, 0): 0, (0, 1, 1): 0,
                (1, 0, 0): 1, (1, 0, 1): 0, (1, 1, 0): 1, (1, 1, 1): 0}
truth_rows = []
for request_n, contract_n, path_invalid_n, power_good in itertools.product((0, 1), repeat=4):
    nor_output = int(not (request_n or contract_n or path_invalid_n))
    enn = gate98_table[(power_good, 0, nor_output)]
    permitted = request_n == contract_n == path_invalid_n == 0 and power_good == 1
    assert (enn == 0) == permitted
    truth_rows.append(dict(request_n=request_n, contract_15_n=contract_n, path_invalid_n=path_invalid_n, power_good=power_good, enn=enn))

reset_load_ua = 1.7 / (180000 * 0.99) * 1e6 + 5
power_good_high_at_3v = 3.0 - 5e-6 * 180000 * 1.01
diode_shift_low_at_25c = 0.4 + 0.32
assert reset_load_ua < 15  # TI POR VOL guarantee load, including negative input leakage
assert power_good_high_at_3v > 1.87  # gate98 VT+ max at VCC=3V
assert 0.3 < 0.35  # POR low versus gate98 VT- min at VCC=1.65V
assert diode_shift_low_at_25c < 0.84  # Schmitt VT- min at VCC=3V
enn_sink_ma = 3.36 / (10000 * 0.99) * 1000 + 0.010
assert enn_sink_ma < 16 and 0.45 < 0.3 * 3.0
assert 2.1 > 1.65 > 0.7  # TMC minimum rising reset > logic min > supervisor POR max

scenarios = [
    dict(name='data only / no logic supply', logic_powered=False, motor_powered=False, motor_enabled=False),
    dict(name='PD5V, with or without data', inputs=[0, 1, 0, 1], enn=1),
    dict(name='PD15V, no request', inputs=[1, 0, 0, 1], enn=1),
    dict(name='PD15V, qualified request', inputs=[0, 0, 0, 1], enn=0),
    dict(name='detach with stale POWER_OK2 and held-up logic', inputs=[0, 0, 1, 1], enn=1),
    dict(name='renegotiation/path loss', inputs=[0, 0, 1, 1], enn=1),
    dict(name='supervisor reset/brownout, any flags', inputs=[0, 0, 0, 0], enn=1),
    dict(name='factory20V configuration', nvm_acceptance=False, fabrication_configuration_acceptance=False),
]
report = dict(circuit_sha256=hashlib.sha256(circuit_bytes).hexdigest(), chosen_gate='TI SN74LVC1G98DCKR C485081, Schmitt-input NAND configuration',
              passed_pin_truth_and_scoped_static_corners=True, truth_rows=truth_rows, scenarios=scenarios,
              corners=dict(supervisor_max_sink_ua=reset_load_ua, supervisor_guarantee_ua=15, power_good_min_high_at_3v=power_good_high_at_3v,
                           pd_diode_shift_max_low_at_25c=diode_shift_low_at_25c, pd_schmitt_low_limit_at_3v=0.84, enn_max_sink_ma=enn_sink_ma,
                           enn_gate_max_low_at_3v=0.45, tmc_low_limit_at_3v=0.9),
              startup_conclusion='No MOS threshold assumption remains. Supervisor feeds a Schmitt input; rising sub-POR is below the TMC minimum I/O reset-release voltage. ENN and VCC_IO share one rail.',
              limitations=['ST open-drain VOL and BAT54 VF/leakage limits used here are guaranteed at25C; hot/cold diode-shift margins require physical qualification.',
                           'Below1.65V logic behavior is outside its operating range. No measured falling-ramp reset threshold or full-ramp waveform is claimed.',
                           'NVM cold readback, live15V negotiation, exact routed input capacitance/edge checks, detach timing and backfeed measurements remain pending.'],
              physical_startup_tested=False, fabrication_ready=False)
report_path.write_text(json.dumps(report, indent=2) + '\n')
print('16 manufacturer truth combinations and scoped static electrical corners pass; physical startup/PD tests remain pending.')

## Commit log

2026-10-02 Select official 14HM11-0404S motor reference and retire incompatible rear mount
    [14HM11-0404S.STEP, 3323_0.stp, AS5600_ASOM.obj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]
2026-10-02 Record checked motor reference source revision
2026-10-02 Expose controller PCB with motor raised in exploded preview
2026-10-03 Expand NEMA14 controller and preserve blocked unrouted validation
    [AP63203WU_7.obj, AP63203WU_7.step, A_0402WGF0000TCE.obj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]
2026-10-03 Attach and validate exact USB4110 external STEP without changing supplier footprint
    [REVIEW-BOM.csv, usb4110-gf-a.stp]
2026-10-03 Recheck motor controller with released CLI and EasyEDA imports; record prototype gates
    [MOTOR-CONNECTOR-FOOTPRINT-AUDIT.json, REVIEW-BOM.csv]
2026-10-03 Add four-point front carrier and audit mounted controller clearance
    [REVIEW-BOM.csv, carrier-fastener-envelopes.step, front-flange-carrier.step]
2026-10-03 Record verified revision 14 source and CAD publication
2026-10-03 Replace input protection and qualify official power imports
    [A_0402WGF2402TCE.obj, A_0402WGF2402TCE.step, DMG1012T_7.obj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]
2026-10-03 Record verified revision 15 source and CAD publication
2026-10-03 Qualify pre-routing prototype limits and four-support carrier
    [REVIEW-BOM.csv, carrier-fastener-envelopes.step, front-flange-carrier.step]
2026-10-03 Preserve checked partial routing and correct native USB via contacts
    [board.dsn, board.kicad_pcb, ground-plane-routed.kicad_pcb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]
2026-10-03 Record verified private publication of routing prototype patch
2026-10-04 Connect ground and isolated eFuse returns with checked copper margins
    [board.kicad_pcb, kicad-native.dsn, routing-interchange.kicad_pcb]
2026-10-04 Bound prototype publication scope and preserve archived evidence hashes
2026-10-04 Record verified prototype 18 source publication and open fabrication gates
2026-10-04 Record prototype 19 distribution scope and archived failure hashes
2026-10-04 Record verified prototype 19 publication and pending fabrication qualification
2026-10-04 Review outward connector openings and mounted cable access in 3D
2026-10-04 Record verified connector audit publication for prototype release
2026-10-04 Publish public prototype circuit JSON and retain build failure evidence
2026-10-05 Fix RAW VBUS neck and complete UART TX with checked native copper
2026-10-05 Align published preview JSON with the checked canonical circuit
2026-10-05 Complete CC1 routing with checked ground and RTN returns
2026-10-05 Complete CC2 with preserved power and USB reference copper
2026-10-05 Complete protected VBUS ADC copper with reviewed escapes
2026-10-05 Record matching public ADC revision and source checksums
2026-10-05 feat(board): complete checked LED status drive routing
2026-10-05 docs(board): verify public LED routing revision and retained native evidence
2026-10-05 feat(board): complete checked external enable connector routing
2026-10-05 docs(board): verify matching public external enable revision
2026-10-05 feat(board): complete checked limit input connector routing
2026-10-05 docs(board): verify matching public limit connector revision
2026-10-05 feat(board): complete internal external-enable copper at revision 28
2026-10-05 docs(board): verify matching public internal-enable revision
2026-10-05 feat(board): complete temperature alert copper at revision 29
2026-10-05 docs(board): verify matching public temperature revision
2026-10-05 feat(board): complete I2C data copper at revision 30
2026-10-05 docs(board): verify matching public I2C data revision
2026-10-05 feat(board): connect LIMIT1 using reviewed native saved routes
2026-10-05 docs(board): verify public LIMIT1 revision and Cloud smoke
2026-10-05 fix(board): qualify motor widths and preserve fixed access copper
    [COMPACT-AND-MOTOR-REPAIRED-PATHS.json, MOTOR-POWER-WIDTH-REVIEW.json, MOTOR-WIDTH-CORRECTED-CANDIDATES.json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]
2026-10-05 docs(board): verify public power repair and Cloud smoke
2026-10-05 fix: complete driver enable and preserve native via obstacles
2026-10-05 docs: record verified driver-enable prototype publication
2026-10-05 fix(board): complete SWDIO guard link and select Pipeline9 consistently
    [REVIEW-BOM.csv]
2026-10-05 fix: restore published CAD dependencies and enforce asset coverage
2026-10-05 docs: record verified public CAD publication repair
2026-10-06 feat: complete native board routing and record ordering blockers
    [REVIEW-BOM.csv, board.kicad_pcb, kicad-native.dsn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]
2026-10-06 docs: record verified board publication and ordering blockers
2026-10-06 docs: retain verified six-point board review publication
2026-10-06 fix: update tscircuit and qualify motor copper and programmer paths
    [MOTOR-CONNECTOR-FOOTPRINT-AUDIT.json, REVIEW-BOM.csv]
2026-10-06 fix: align ground escape CAM and clear connector legends
    [REVIEW-BOM.csv]
2026-10-06 Explain every component on the nine native schematic sheets
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2026-10-06 feat(schematic): use standard USB-C symbol and correct reference labels
2026-10-06 chore(publication): ship current review evidence without historical duplicates
2026-10-06 feat(board): remove unused AS5600 encoder and preserve temperature bus
    [REVIEW-BOM.csv]
2026-10-06 docs(board): record revision 40 publication and Linux verification
2026-10-06 Replace unavailable driver and USB protector with verified official parts
    [REVIEW-BOM.csv, TMC2209_LA_T.obj, TMC2209_LA_T.step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]
2026-10-06 Review remaining fabrication gates and motor copper losses
    [MOTOR-COPPER-LOSS.json]
2026-10-06 Fix ten native schematic style issues without changing board copper
    [B_Cu.gbr, B_Fab.gbr, B_Mask.gbr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]
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2026-10-06 fix: resize ordinary via pads and qualify power and buzzer trials
    [B_Cu.gbr, B_Fab.gbr, B_Mask.gbr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]
2026-10-06 feat: redesign controller with RP2040 and autonomous USB-PD
    [ABM8_16_000MHZ_B2_T.obj, ABM8_16_000MHZ_B2_T.step, ABM8_272_T3.obj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]
2026-10-07 test: audit CadQuery solids and expose flash model blocker
    [J_SWD.step]
2026-10-07 Implement reviewed RP2040 USB-PD prototype and qualify 44 connected nets
    [A_0402WGF270JTCE.obj, A_0402WGF270JTCE.step, B5819WS.obj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]
2026-10-07 Record matching public RP2040 prototype release checksum verification
2026-10-07 Route RP2040 debug and CAN clocks with checked ordinary vias
    [A_0402CG300J500NT.obj, A_0402CG300J500NT.step, REVIEW-BOM.csv]
2026-10-07 Record verified public revision46 package and CAD checksums
2026-10-07 Save corrected Pipeline9 CAN routes and outer motor winding
2026-10-07 Record exact public revision47 source and CAD verification
2026-10-07 Save checked CAN and programmer Pipeline9 routes with manual clearance repairs
    [motor106-explicit.json, motor109-explicit.json, motor111-explicit.json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]
2026-10-07 Record verified public revision48 Circuit JSON and CAD publication
2026-10-07 Implement two-port RP2040 15V-PD prototype with qualified partial copper
    [A_0402WGF1803TCE.obj, A_0402WGF1803TCE.step, A_0402WGF5101TCE.obj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]
2026-10-07 Complete PD FET source routes and qualify TMC thermal vias
    [MOTOR-INTERLOCK.json]
2026-10-07 Connect protected VBUS and all VM terminals with qualified native copper
    [MOTOR-INTERLOCK.json]
2026-10-07 Record exact public revision 52 source and CAD verification
2026-10-08 Route local RP2040 power branches and correct manufacturing records
    [MOTOR-INTERLOCK.json]
2026-10-08 Record verified revision 53 public source and CAD receipt
